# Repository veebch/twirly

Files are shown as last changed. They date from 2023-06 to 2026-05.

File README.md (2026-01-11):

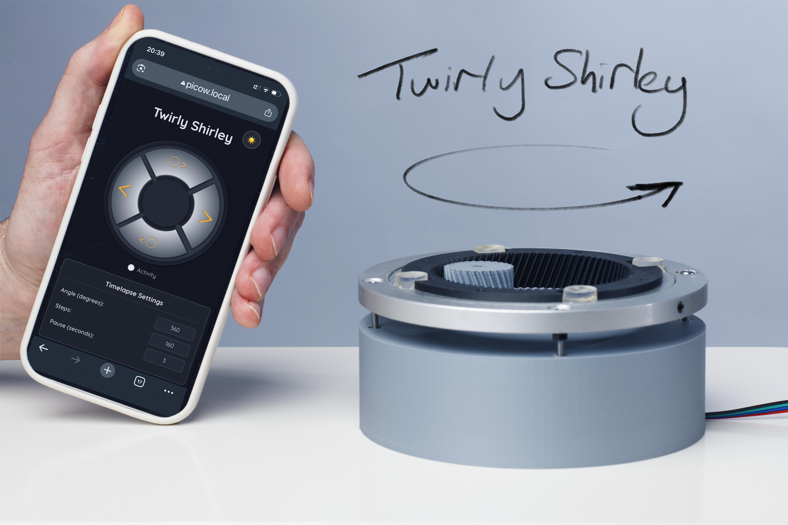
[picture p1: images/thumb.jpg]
Action Shot


 

# Twirly Shirley - WiFi Turntable

A webpage-controlled turntable system using Raspberry Pi Pico W and DRV8825 stepper motor driver. Perfect for product photography, 360° documentation, time-lapse videos and rotating things remotely.

## Demo Video

*Click [here](https://www.youtube.com/watch?v=peo0DxWtorY) to watch the full demonstration*

## Web Interface

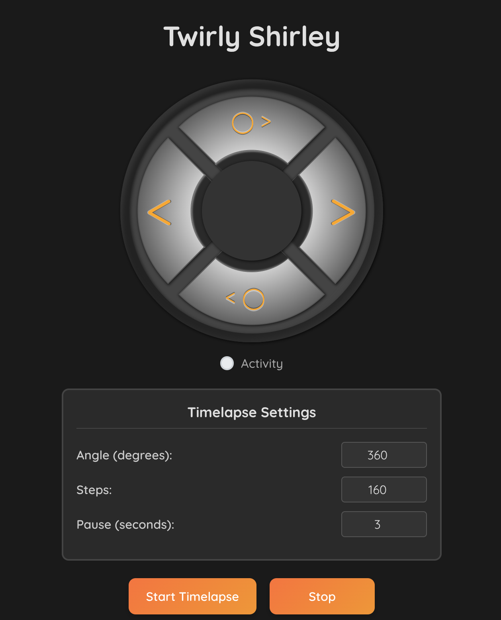
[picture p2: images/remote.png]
Remote Control Interface


The mobile-friendly web interface provides complete control over the turntable with real-time feedback and dark mode support.

## Quick Start

1. **Flash MicroPython** to your Pico W
2. **Wire the hardware** - see [WIRING.md](WIRING.md) for detailed connections
3. **Copy files** to the Pico W filesystem
4. **Power on** - Twirly will automatically start an access point for WiFi setup
5. **Connect to "pi pico" WiFi** and configure your network credentials
6. **Access** the web interface at http://picow.local 

## Key Features

- **Microstepping Control**: Smooth motion with 1-32 microstepping
- **Web Interface**: Mobile-friendly with dark mode
- **Timelapse Mode**: Automated rotation for photography
- **Network Access**: WiFi with mDNS hostname (http://picow.local) 
## Documentation

| Guide | Description |
|---|---|
| [WIRING.md](WIRING.md) | Hardware connections and setup |
| [FEATURES.md](FEATURES.md) | Complete feature list and configuration |
| [TROUBLESHOOTING.md](TROUBLESHOOTING.md) | Common issues and solutions |

## License

This project is licensed under the MIT License - see the [LICENSE](LICENSE) file for details.

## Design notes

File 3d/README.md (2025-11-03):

Action Shot

# Gears and Case

These stl files were made with [openSCAD](https://openscad.org/) and Freecad. The script that generated the stl files is also here in case you need to tweak things due to using different parts. The gears script was based on was written by @chrisspen (https://github.com/chrisspen/gears)

To regenerate the two gears, use openscad to render the gear (uncomment ringgear or wormgear) which you can then import into your CAD tool of choice (+1 for [FreeCAD](https://freecad.org)) for tweaks to the design.

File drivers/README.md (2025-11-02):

# Drivers Directory

This directory contains all the hardware driver files and technical documentation for the Twirly project.

## Core Files

- **`drv8825.py`** - Main DRV8825 stepper motor driver class
- **`drv8825_setup.py`** - Hardware initialization and configuration

## Test and Example Files

- **`drv8825_followme.py`** - Interactive control example
- **`drv8825_speeds.py`** - Speed testing utilities  
- **`drv8825_steps.py`** - Step counting examples
- **`drv8825_turns.py`** - Rotation testing
- **`test_microstepping.py`** - Microstepping validation

## Additional Hardware

- **`encoder_portable.py`** - Rotary encoder support
- **`switch.py`** - Switch/button utilities

## Documentation

- **`MICROSTEPPING_GUIDE.md`** - Technical guide to microstepping configuration

## Usage

These files are imported by the main application. The primary entry point is `drv8825_setup.py` which initializes the motor hardware.

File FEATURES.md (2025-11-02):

# Features Guide

This guide details all the features and configuration options available in the turntable controller.

## Motor Control Features

### Microstepping Control

The system supports variable microstepping resolution for smooth motion control:

| Microsteps | Resolution | Description |
|---|---|---|
| 1 (full) | 1.8°/step | Maximum torque, fastest movement |
| 2 (half) | 0.9°/step | Good balance of speed and smoothness |
| 4 (quarter) | 0.45°/step | Smoother than half-step |
| 8 (eighth) | 0.225°/step | Very smooth operation |
| 16 | 0.1125°/step | Ultra-smooth, recommended default |
| 32 | 0.05625°/step | Maximum smoothness, slower movement |

**Configuration**: Set via web interface or modify `MICROSTEPS` in `main.py`

### Speed Ramping

3-phase acceleration/deceleration system for smooth starts and stops:

1. **Acceleration Phase**: Gradually increases from start speed to target speed
2. **Constant Speed Phase**: Maintains target speed for majority of movement
3. **Deceleration Phase**: Gradually decreases to stop speed

**Benefits**:
- Prevents motor stalling on startup
- Reduces mechanical stress
- Eliminates abrupt stops
- Smoother operation for photography/videography

### Gear Ratio Compensation

Automatic adjustment for mechanical gear reduction systems:

**Default Configuration**:
- Motor gear: 20 teeth
- Turntable gear: 81 teeth  
- Gear ratio: 4.05:1

**Customization**: Modify `GEAR_RATIO` in `main.py`:
```python
GEAR_RATIO = large_gear_teeth / small_gear_teeth
```

**Effects**:
- All rotation commands automatically compensated
- Maintains accurate angular positioning
- 360° rotation produces exactly one turntable revolution

### Direction Control

- **Clockwise**: Positive rotation values
- **Counter-clockwise**: Negative rotation values
- **Automatic**: Direction determined by rotation angle

## Web Interface Features

### Responsive Design

- **Desktop Optimized**: Full-featured interface with large controls
- **Mobile Friendly**: Touch-optimized buttons and responsive layout
- **Cross-Browser**: Compatible with modern browsers

### Dark Mode

Complete theming system with automatic preference saving:

**Features**:
- Toggle between light and dark themes
- Automatic preference persistence using localStorage
- Optimized for low-light environments
- Professional appearance for studio use

**Controls**:
- Click moon/sun icon to toggle
- Preference remembered across browser sessions
- Instant theme switching without page reload

### Real-time Control

**Manual Controls**:
- Step-by-step movement (1° increments)
- Quick rotation presets (90°, 180°, 270°, 360°)
- Direction control (CW/CCW)
- Emergency stop functionality

**Live Updates**:
- Current position display
- Motor status indicators
- Network connectivity status
- Real-time feedback on all operations

### Timelapse Mode

Automated rotation system for time-lapse photography:

**Parameters**:
- **Total Rotation**: 360° (full rotation) or custom angle
- **Number of Steps**: Configurable step count for desired frame rate
- **Delay Between Steps**: Pause time for camera exposure
- **Direction**: Clockwise or counter-clockwise

**Progress Tracking**:
- Real-time step counter (Step X of Y)
- Estimated time remaining
- Visual progress indicators
- Abort capability at any time

**Use Cases**:
- Product photography turntables
- 360° object documentation
- Time-lapse videos with rotation
- Automated scanning applications

## Network Features

### WiFi Connectivity

**Primary Mode**: Connects to existing WiFi network
- Automatic connection on startup
- DHCP IP assignment
- Status LED indication

**Configuration**: Edit WiFi credentials in `main.py`:
```python
WIFI_SSID = "your_network_name"
WIFI_PASSWORD = "your_password"
```

### Access Point Fallback

**Backup Mode**: Creates standalone network when WiFi unavailable
- Network name: "Twirly"
- IP address: 192.168.4.1
- No password required
- Automatic activation on WiFi failure

### mDNS Support

**Easy Access**: Device accessible via friendly name
- URL: `http://twirly.local`
- No need to remember IP addresses
- Automatic discovery on local network
- Compatible with most modern devices

## Status Indicators

### Activity LED

Visual feedback system using onboard LED:

**Network Status**:
- **Solid ON**: Connected to WiFi
- **Slow Blink**: Access Point mode active
- **Fast Blink**: Network connection attempt

**Motor Activity**:
- **Brief Flash**: Step command executed
- **Longer Flash**: Multi-step operation
- **Duration**: Configurable via `LED_DURATION_MS`

## Configuration Options

### Motor Parameters

Located in `main.py`, easily customizable:

```python
# Microstepping configuration
MICROSTEPS = 16          # Default microstepping resolution

# Gear system
GEAR_RATIO = 81/20       # Mechanical gear reduction

# Speed settings
MAX_SPEED = 2000         # Maximum steps per second
START_SPEED = 200        # Initial ramp speed
ACCELERATION = 1000      # Steps/second² acceleration

# LED behavior  
LED_DURATION_MS = 100    # Activity flash duration
```

### Network Settings

```python
# WiFi configuration
WIFI_SSID = "your_network"
WIFI_PASSWORD = "your_password"

# Access point fallback
AP_SSID = "Twirly"
AP_PASSWORD = None       # Open network
```

### Hardware Pins

All pin assignments configurable in `drv8825_setup.py`:

```python
# Motor control pins
STEP_PIN = 2
DIR_PIN = 3  
ENABLE_PIN = 4

# Microstepping pins
M0_PIN = 6
M1_PIN = 7
M2_PIN = 8
```

## Advanced Features

### Position Tracking

- Maintains current angular position
- Accurate step counting with microstepping
- Position reset capability
- Overflow protection for continuous operation

### Error Handling

- Network timeout protection
- Motor fault detection
- Graceful degradation on errors
- Automatic recovery mechanisms

### Performance Optimization

- Efficient step timing for DRV8825 compatibility
- Minimal latency web responses
- Optimized ramp calculations
- Memory-efficient operation on microcontroller

## Extensibility

The modular design allows easy customization:

**Hardware Extensions**:
- Additional sensors (limit switches, encoders)
- Different motor drivers
- External control interfaces

**Software Modifications**:
- Custom web interface themes
- Additional movement patterns
- Integration with external systems
- Custom API endpoints

**Communication Options**:
- Serial control interface
- MQTT integration potential
- REST API expansion
- WebSocket real-time updates

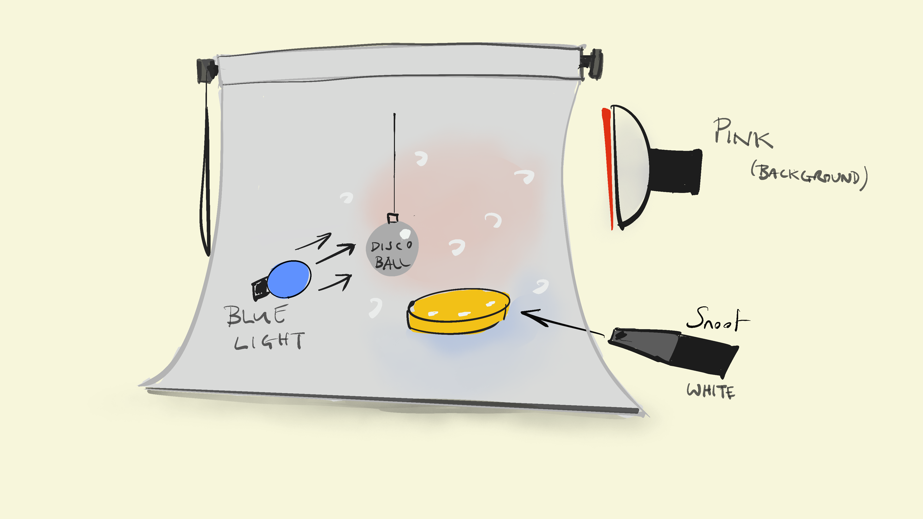
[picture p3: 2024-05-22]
images/lighting.png

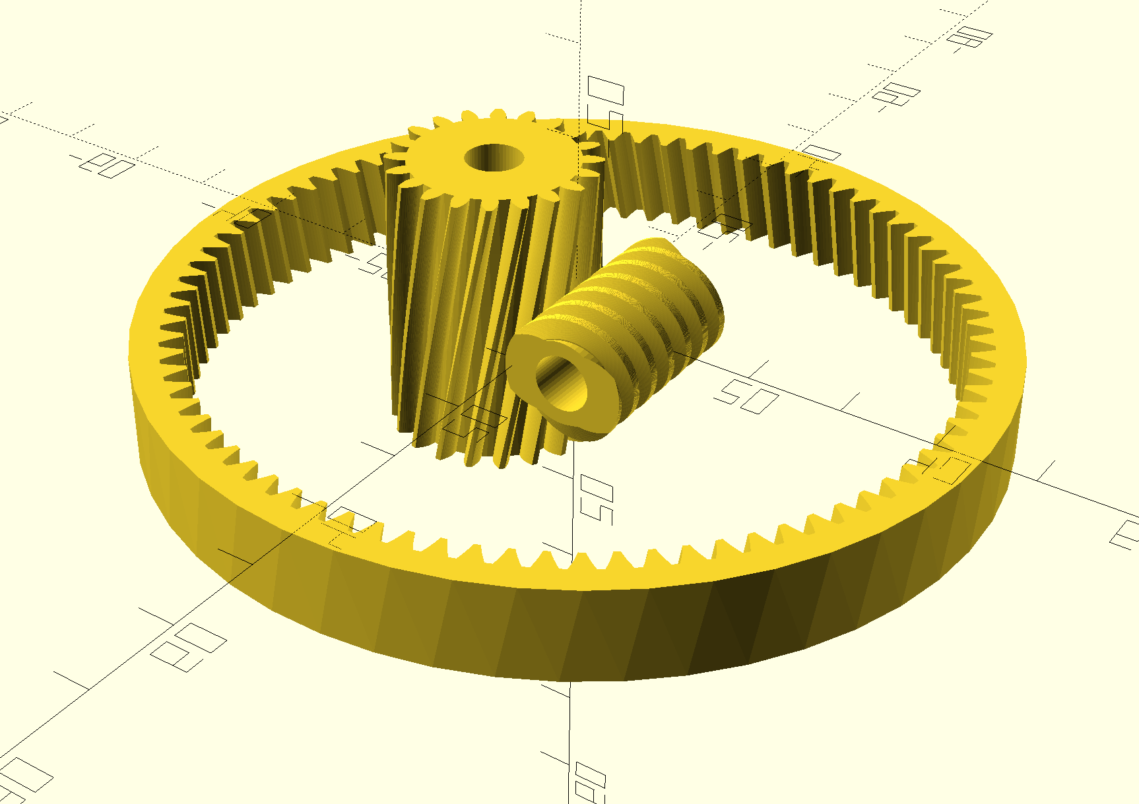
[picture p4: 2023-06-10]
images/gears.png

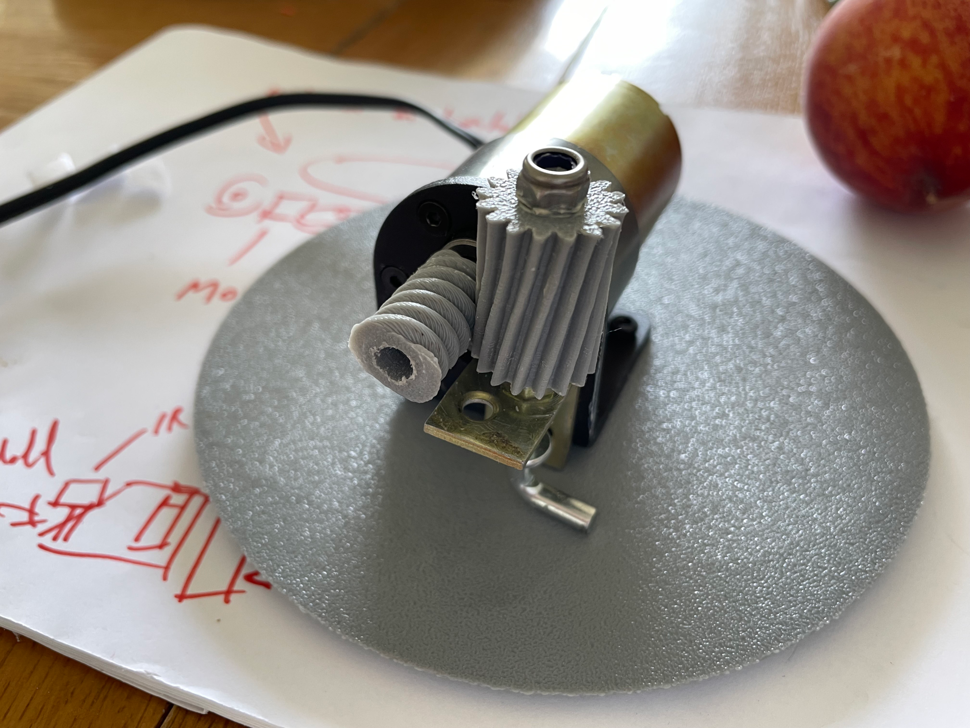
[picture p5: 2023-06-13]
images/motorworm.png

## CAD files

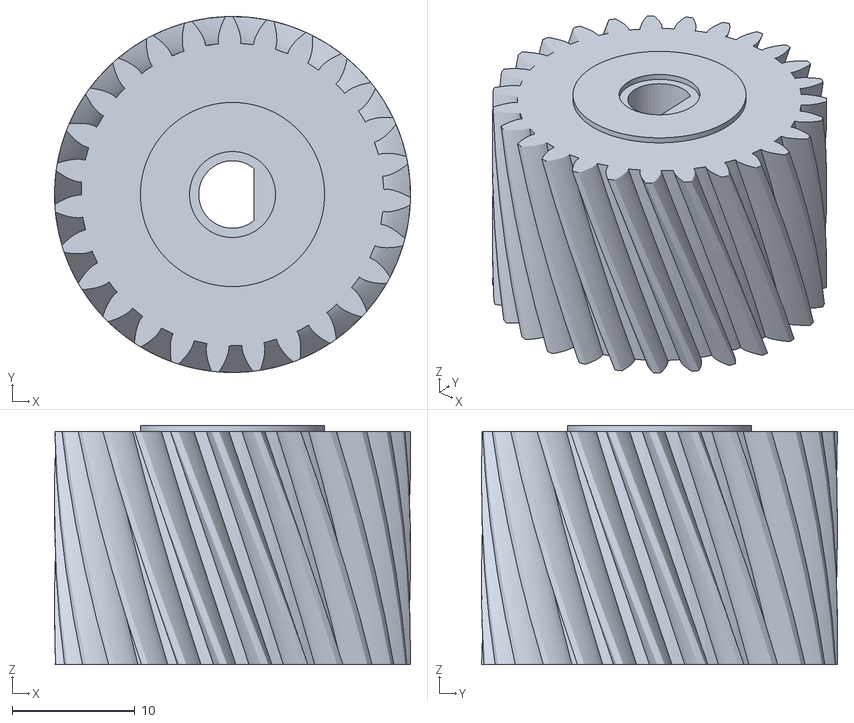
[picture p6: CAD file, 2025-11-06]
3d/gear.stl
29.0 x 29.0 x 19.5

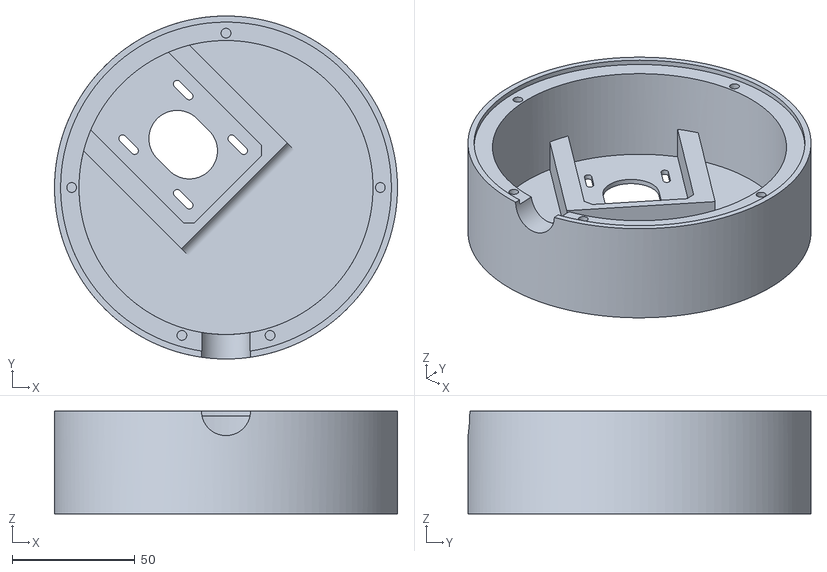
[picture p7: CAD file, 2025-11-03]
3d/twirlycase.stl
140.0 x 140.0 x 42.0

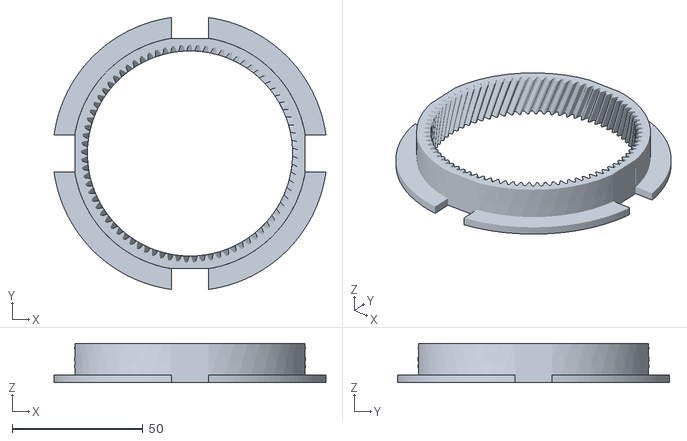
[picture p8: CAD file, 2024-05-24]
3d/ringgear.stl
104.1 x 104.1 x 15.0

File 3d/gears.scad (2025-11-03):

$fn = 50;

/* Library for Involute Gears, Screws and Racks

This library contains the following modules
- rack(modul, length, height, width, pressure_angle=20, helix_angle=0)
- mountable_rack(modul, length, height, width, pressure_angle=20, helix_angle=0, fastners, profile, head)
- herringbone_rack(modul, length, height, width, pressure_angle = 20, helix_angle=45)
- mountable_herringbone_rack(modul, length, height, width, pressure_angle=20, helix_angle=45, fastners, profile, head)
- spur_gear(modul, tooth_number, width, bore, pressure_angle=20, helix_angle=0, optimized=true)
- herringbone_gear(modul, tooth_number, width, bore, pressure_angle=20, helix_angle=0, optimized=true)
- rack_and_pinion (modul, rack_length, gear_teeth, rack_height, gear_bore, width, pressure_angle=20, helix_angle=0, together_built=true, optimized=true)
- ring_gear(modul, tooth_number, width, rim_width, pressure_angle=20, helix_angle=0)
- herringbone_ring_gear(modul, tooth_number, width, rim_width, pressure_angle=20, helix_angle=0)
- planetary_gear(modul, sun_teeth, planet_teeth, number_planets, width, rim_width, bore, pressure_angle=20, helix_angle=0, together_built=true, optimized=true)
- bevel_gear(modul, tooth_number,  partial_cone_angle, tooth_width, bore, pressure_angle=20, helix_angle=0)
- bevel_herringbone_gear(modul, tooth_number, partial_cone_angle, tooth_width, bore, pressure_angle=20, helix_angle=0)
- bevel_gear_pair(modul, gear_teeth, pinion_teeth, axis_angle=90, tooth_width, bore, pressure_angle = 20, helix_angle=0, together_built=true)
- bevel_herringbone_gear_pair(modul, gear_teeth, pinion_teeth, axis_angle=90, tooth_width, bore, pressure_angle = 20, helix_angle=0, together_built=true)
- worm(modul, thread_starts, length, bore, pressure_angle=20, lead_angle=10, together_built=true)
- worm_gear(modul, tooth_number, thread_starts, width, length, worm_bore, gear_bore, pressure_angle=20, lead_angle=0, optimized=true, together_built=true)

Examples of each module are commented out at the end of this file

Author:     Dr Jörg Janssen
Contributions By:   Keith Emery, Chris Spencer
Last Verified On:      1. June 2018
Version:    2.2
License:     Creative Commons - Attribution, Non Commercial, Share Alike

Permitted modules according to DIN 780:
0.05 0.06 0.08 0.10 0.12 0.16
0.20 0.25 0.3  0.4  0.5  0.6
0.7  0.8  0.9  1    1.25 1.5
2    2.5  3    4    5    6
8    10   12   16   20   25
32   40   50   60

*/


// General Variables
pi = 3.14159;
rad = 57.29578;
clearance = 0.05;   // clearance between teeth

/*  Converts Radians to Degrees */
function grad(pressure_angle) = pressure_angle*rad;

/*  Converts Degrees to Radians */
function radian(pressure_angle) = pressure_angle/rad;

/*  Converts 2D Polar Coordinates to Cartesian
    Format: radius, phi; phi = Angle to x-Axis on xy-Plane */
function polar_to_cartesian(polvect) = [
    polvect[0]*cos(polvect[1]),
    polvect[0]*sin(polvect[1])
];

/*  Circle Involutes-Function:
    Returns the Polar Coordinates of an Involute Circle
    r = Radius of the Base Circle
    rho = Rolling-angle in Degrees */
function ev(r,rho) = [
    r/cos(rho),
    grad(tan(rho)-radian(rho))
];

/*  Sphere-Involutes-Function
    Returns the Azimuth Angle of an Involute Sphere
    theta0 = Polar Angle of the Cone, where the Cutting Edge of the Large Sphere unrolls the Involute
    theta = Polar Angle for which the Azimuth Angle of the Involute is to be calculated */
function sphere_ev(theta0,theta) = 1/sin(theta0)*acos(cos(theta)/cos(theta0))-acos(tan(theta0)/tan(theta));

/*  Converts Spherical Coordinates to Cartesian
    Format: radius, theta, phi; theta = Angle to z-Axis, phi = Angle to x-Axis on xy-Plane */
function sphere_to_cartesian(vect) = [
    vect[0]*sin(vect[1])*cos(vect[2]),
    vect[0]*sin(vect[1])*sin(vect[2]),
    vect[0]*cos(vect[1])
];

/*  Check if a Number is even
    = 1, if so
    = 0, if the Number is not even */
function is_even(number) =
    (number == floor(number/2)*2) ? 1 : 0;

/*  greatest common Divisor
    according to Euclidean Algorithm.
    Sorting: a must be greater than b */
function ggt(a,b) =
    a%b == 0 ? b : ggt(b,a%b);

/*  Polar function with polar angle and two variables */
function spiral(a, r0, phi) =
    a*phi + r0;

/*  Copy and rotate a Body */
module copier(vect, number, distance, winkel){
    for(i = [0:number-1]){
        translate(v=vect*distance*i)
            rotate(a=i*winkel, v = [0,0,1])
                children(0);
    }
}

/*  rack
    modul = Height of the Tooth Tip above the Rolling LIne
    length = Length of the Rack
    height = Height of the Rack to the Pitch Line
    width = Width of a Tooth
    pressure_angle = Pressure Angle, Standard = 20° according to DIN 867. Should not exceed 45°.
    helix_angle = Helix Angle of the Rack Transverse Axis; 0° = Spur Teeth */
module rack(modul, length, height, width, pressure_angle = 20, helix_angle = 0) {

    // Dimension Calculations
    modul=modul*(1-clearance);
    c = modul / 6;                                              // Tip Clearance
    mx = modul/cos(helix_angle);                          // Module Shift by Helix Angle in the X-Direction
    a = 2*mx*tan(pressure_angle)+c*tan(pressure_angle);       // Flank Width
    b = pi*mx/2-2*mx*tan(pressure_angle);                      // Tip Width
    x = width*tan(helix_angle);                          // Topside Shift by Helix Angle in the X-Direction
    nz = ceil((length+abs(2*x))/(pi*mx));                       // Number of Teeth

    translate([-pi*mx*(nz-1)/2-a-b/2,-modul,0]){
        intersection(){                                         // Creates a Prism that fits into a Geometric Box
            copier([1,0,0], nz, pi*mx, 0){
                polyhedron(
                    points=[[0,-c,0], [a,2*modul,0], [a+b,2*modul,0], [2*a+b,-c,0], [pi*mx,-c,0], [pi*mx,modul-height,0], [0,modul-height,0], // Underside
                        [0+x,-c,width], [a+x,2*modul,width], [a+b+x,2*modul,width], [2*a+b+x,-c,width], [pi*mx+x,-c,width], [pi*mx+x,modul-height,width], [0+x,modul-height,width]],   // Topside
                    faces=[[6,5,4,3,2,1,0],                     // Underside
                        [1,8,7,0],
                        [9,8,1,2],
                        [10,9,2,3],
                        [11,10,3,4],
                        [12,11,4,5],
                        [13,12,5,6],
                        [7,13,6,0],
                        [7,8,9,10,11,12,13],                    // Topside
                    ]
                );
            };
            translate([abs(x),-height+modul-0.5,-0.5]){
                cube([length,height+modul+1,width+1]);          // Cuboid which includes the Volume of the Rack
            }
        };
    };
}

/* Mountable-rack; uses module "rack"
    modul = Height of the Tooth Tip above the Rolling LIne
    length = Length of the Rack
    height = Height of the Rack to the Pitch Line
    width = Width of a Tooth
    pressure_angle = Pressure Angle, Standard = 20° according to DIN 867. Should not exceed 45°.
    helix_angle = Helix Angle of the Rack Transverse Axis; 0° = Spur Teeth
    fastners = Total number of fastners.
    profile = Metric standard profile for fastners (ISO machine screws), M4 = 4, M6 = 6 etc.
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

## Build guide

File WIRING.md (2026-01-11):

# Wiring Guide

Raspberry Pi Pico GPIO Pinout

This guide provides detailed wiring instructions for connecting the Raspberry Pi Pico W to the DRV8825 stepper motor driver.

## Required Components

- Raspberry Pi Pico W
- DRV8825 Stepper Motor Driver
- NEMA stepper motor (4-wire bipolar)
- 20V PD trigger (USB-C) for motor power supply
- Step-down converter (20V to 5V) for logic power
- 100µF capacitor (for 20V supply)
- 100µF capacitor (for 5V supply)
- Breadboard or prototype board
- Jumper wires

## Assembled Components

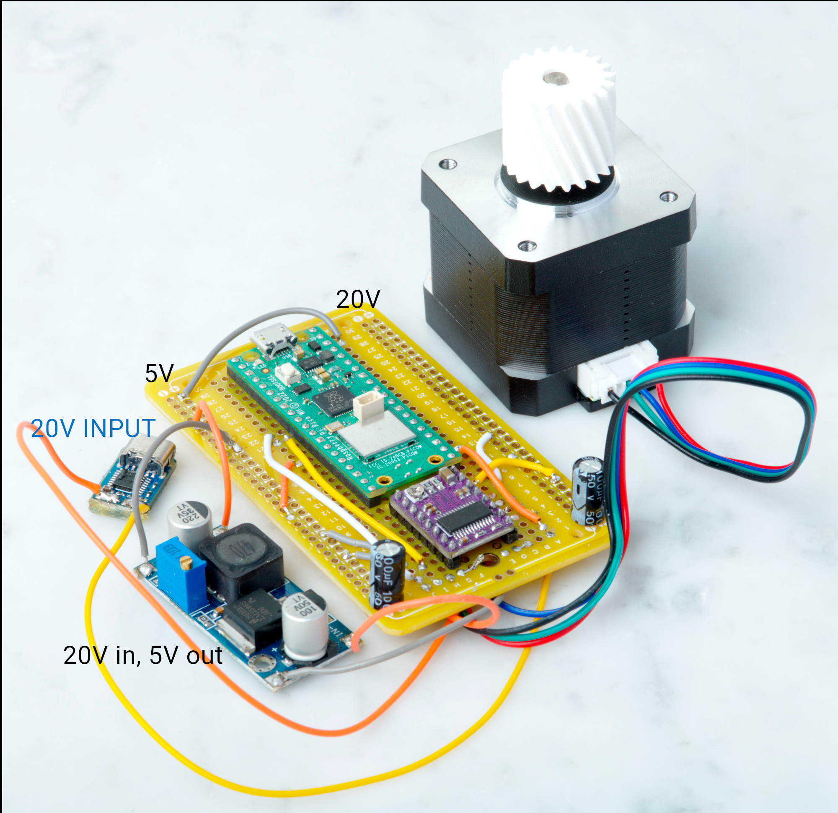
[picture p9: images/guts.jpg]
Assembled Components


*Example of the assembled system showing the Raspberry Pi Pico W, DRV8825 driver, USB-C PD trigger, and step-down converter. NB. Microstepping not connected in this image*

## Pin Connections

### Pico W to DRV8825

| Pico W Pin | DRV8825 Pin | Function |
|---|---|---|
| GP7 | STEP | Step pulse signal |
| GP6 | DIR | Direction control |
| GP8 | SLEEP | Sleep control (motor enable) |
| GP9 | RESET | Reset control |
| GP12 | M0 | Microstepping bit 0 |
| GP11 | M1 | Microstepping bit 1 |
| GP10 | M2 | Microstepping bit 2 |
| GND | GND | Common ground |

### Additional Control Pins (Optional)

| Pico W Pin | Component | Function |
|---|---|---|
| GP2 | Button/Switch | User input button |
| GP14 | End Switch 1 | Position limit switch |
| GP15 | End Switch 2 | Position limit switch |
| GP0 | Rotary Encoder A | Manual control input |
| GP1 | Rotary Encoder B | Manual control input |

### Power Supply Connections

| Connection | Description |
|---|---|
| USB-C PD Trigger 20V+ → VMOT | Motor power from PD trigger |
| USB-C PD Trigger GND → GND | Motor power ground |
| Step-down Converter 5V+ → VDD | Logic power from step-down converter |
| Step-down Converter GND → GND | Logic power ground |

**Power Supply Chain**: USB-C PD Trigger (20V) → Step-down Converter → 5V Logic Supply

### Motor Connections

Connect your 4-wire bipolar stepper motor to the DRV8825 output terminals:
- **2B, 2A**: One motor coil
- **1A, 1B**: Other motor coil

**Important**: All four motor wires must be connected for proper operation. If your motor runs, but is jerky and not in a single direction, this is likely the issue. If your motor runs, but is jerky and not in a single direction, this is likely the issue.

## Microstepping Configuration

The microstepping resolution is controlled by three pins (M0, M1, M2):

| M0 | M1 | M2 | Microsteps | Resolution |
|----|----|----|---|---|
| L  | L  | L  | 1 (full) | 1.8°/step |
| H  | L  | L  | 2 (half) | 0.9°/step |
| L  | H  | L  | 4 (quarter)| 0.45°/step |
| H  | H  | L  | 8 (eighth) | 0.225°/step |
| L  | L  | H  | 16 | 0.1125°/step |
| H  | L  | H  | 32 | 0.05625°/step |

**Note**: H = High (3.3V), L = Low (0V or floating)

## Current Limiting Setup

The DRV8825 has a built-in current limiting feature that must be properly configured:

### Step-by-Step Current Setting

1. **Calculate Target Current**: Check your motor's rated current (typically 1-2A)

2. **Measure Reference Voltage**: 
   - Connect multimeter between GND and the small potentiometer on the DRV8825
   - Measure the voltage while the driver is powered

3. **Calculate Required Voltage**:
   ```
   VREF = Current_Limit × 8 × Rsense
   ```
   For DRV8825: `VREF = Current_Limit × 8 × 0.1 = Current_Limit × 0.8`
   
   Example: For 1.5A current limit: `VREF = 1.5 × 0.8 = 1.2V`

4. **Adjust Potentiometer**: 
   - Use a small screwdriver to turn the potentiometer
   - Clockwise increases current, counter-clockwise decreases
   - Adjust until VREF matches your calculated value

### Important Safety Notes

- Set current limit BEFORE connecting the motor
- Start with a lower current and increase gradually
- Monitor motor temperature during operation
- The driver will get warm during normal operation

## Power Supply Filtering

Add capacitors near the DRV8825 to filter power supply noise:

- **100µF capacitor**: Connect across 20V PD trigger output (VMOT to GND)
- **100µF capacitor**: Connect across 5V step-down converter output (VDD to GND)

These capacitors smooth voltage fluctuations and protect against voltage spikes from the USB-C PD trigger and step-down converter.

## Wiring Checklist

Before powering on, verify:

- [ ] All pin connections are secure
- [ ] Power supply polarities are correct
- [ ] Motor wires are properly connected (all 4 wires)
- [ ] Current limit is set appropriately
- [ ] Capacitors are installed for power filtering
- [ ] No short circuits between power rails
- [ ] Common ground connections are established

## Common Wiring Issues

- **Motor not moving**: Check that all 4 motor wires are connected
- **Erratic movement**: Verify power supply filtering and current limit setting
- **Driver overheating**: Reduce current limit or improve heat dissipation
- **No response**: Check enable pin connection and power supplies

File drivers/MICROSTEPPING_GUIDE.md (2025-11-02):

# Microstepping Enhancement Guide

## Overview

This turntable project has been enhanced to use **microstepping** with **intelligent speed ramping** for smoother, more precise motor control. Microstepping divides each full step of the stepper motor into smaller increments, while speed ramping provides smooth acceleration and deceleration curves.

## Key Features

### Microstepping Benefits:
- **Smoother motion** with reduced vibration
- **Higher precision** positioning
- **Quieter operation**
- **Better low-speed performance**

### Speed Ramping Benefits:
- **Gentle acceleration/deceleration** prevents mechanical stress
- **Eliminates jerky starts/stops**
- **Reduces lost steps** at high speeds
- **Professional-quality motion** for photography/videography

## Microstepping Options

The DRV8825 driver supports the following microstepping resolutions:

| Microsteps | Resolution | Use Case | Ramping Applied |
|---|---|---|---|
| 1 | Full step | Maximum speed, basic positioning | Large moves only |
| 2 | Half step | Good balance of speed and smoothness | Large moves only |
| 4 | Quarter step | Better smoothness | Large moves only |
| 8 | 1/8 step | High precision applications | Most moves |
| 16 | 1/16 step | **Default** - Excellent smoothness | All large moves |
| 32 | 1/32 step | Maximum smoothness, slower speed | All moves |

## Speed Ramping Implementation

### When Ramping is Applied:
- **360° rotations**: Full ramping for smooth professional motion
- **Timelapse sequences**: Ramping on each movement for cinematic quality
- **Large movements**: Movements > 20 full steps equivalent
- **Small nudges**: No ramping for precise positioning
- **Tiny adjustments**: Movements < 6 full steps equivalent

### Ramping Profile:
1. **Acceleration Phase**: 15% of movement at 30-100% target speed
2. **Constant Phase**: 70% of movement at target speed
3. **Deceleration Phase**: 15% of movement at 100-30% target speed

## Web Interface Controls

### Basic Motor Controls
- **< and >**: Small nudge movements
- **◯ > and < ◯**: Full 360° rotations  
- **Title**: Timelapse sequence with ramping
- **Center button**: Emergency stop

### Microstepping Settings
- **Settings panel**: Choose from 1, 2, 4, 8, 16, or 32 microsteps
- **Status display**: Shows current microstepping configuration
- **Real-time switching**: Change settings without restarting

## API Endpoints

### Movement Controls
- `GET /cw_360` - Clockwise 360° rotation **with ramping**
- `GET /ccw_360` - Counter-clockwise 360° rotation **with ramping**
- `GET /cw_a_bit` - Small clockwise nudge **without ramping**
- `GET /ccw_a_bit` - Small counter-clockwise nudge **without ramping**
- `GET /timelapse` - Execute timelapse sequence **with ramping**
- `GET /stop` - Emergency stop

### Configuration & Testing
- `GET /microsteps?microsteps=<value>` - Set microstepping (1,2,4,8,16,32)
- `GET /microsteps` - Get current microstepping setting
- `GET /status` - Get system status including microstepping and ramping info
- `GET /test_ramping` - **NEW**: Test ramping functionality with controlled sequence

## Technical Implementation

### Speed Optimization with Ramping
The system automatically adjusts speeds and applies ramping based on microstepping resolution:

```python
# Speed scaling based on microstepping
speed = base_speed * (current_microsteps // 4)

# Intelligent ramping decision
if movement_size > microsteps * 20:
    action(steps, microsteps, speed, use_ramping=True)
else:
    action(steps, microsteps, speed, use_ramping=False)
```

### Ramping Algorithm
```python
# Three-phase movement for large motions:
# 1. Acceleration: 30% → 100% of target speed
# 2. Constant: 100% of target speed  
# 3. Deceleration: 100% → 30% of target speed
```

### Step Calculation
Physical movements are maintained by scaling step counts:

```python
# Same physical movement regardless of microstepping
steps = full_steps * current_microsteps
```

### Hardware Connections (Raspberry Pi Pico W)
- M0 pin: GPIO 12
- M1 pin: GPIO 11  
- M2 pin: GPIO 10
- STEP pin: GPIO 7
- DIR pin: GPIO 6
- SLEEP pin: GPIO 8
- RESET pin: GPIO 9

## Usage Examples

### Changing Microstepping via Web Interface
1. Open the turntable web interface
2. Use the microstepping buttons (1, 2, 4, 8, 16, 32)
3. Current setting is highlighted in orange
4. All subsequent movements use the new setting

### Changing Microstepping via API
```bash
# Set to 16 microsteps for smooth operation
curl "http://[pico-ip]/microsteps?microsteps=16"

# Set to 1 microstep for maximum speed
curl "http://[pico-ip]/microsteps?microsteps=1"

# Check current setting
curl "http://[pico-ip]/status"
```

### Testing Speed Ramping via API
```bash
# Test the ramping functionality
curl "http://[pico-ip]/test_ramping"

# Check system status (includes ramping info)
curl "http://[pico-ip]/status"
```

### Code Example with Ramping
```python
# Large movement with automatic ramping
action(steps=810 * 16, microsteps=16, speed=400, use_ramping=True)

# Small precise movement without ramping  
action(steps=6 * 8, microsteps=8, speed=200, use_ramping=False)

# Let system decide based on movement size
action(steps=100 * 16, microsteps=16, speed=300)  # Auto-ramping
```

## Recommendations

### For Different Use Cases:

**Photography/Videography**: Use 16 or 32 microsteps with ramping enabled for smooth, professional motion that eliminates camera shake

**Product Scanning**: Use 8 or 16 microsteps with ramping for good precision and smooth movement between positions

**Quick Positioning**: Use 1 or 2 microsteps - ramping automatically disabled for small moves, enabled for large moves

**Precision Work**: Use 16 or 32 microsteps with ramping for fine adjustments without vibration

### Performance Notes:
- **Ramping automatically applied** to movements > 20 full-step equivalent
- **Small nudges skip ramping** for immediate precise positioning  
- **Emergency stop works immediately** regardless of ramping state
- **Speed scaling optimized** for each microstepping level
- **Three-phase ramping** provides professional motion quality

### Motion Quality Comparison:
- **Without ramping**: Instant start/stop, possible vibration, good for tiny adjustments
- **With ramping**: Smooth acceleration/deceleration, professional quality, ideal for visible movements

## Troubleshooting

### Motor Not Moving
1. Check microstepping setting (try setting to 1 for testing)
2. Verify power supply (20V for motor, 5V for logic)
3. Check wiring connections
4. Test with lower speeds

### Jerky Movement
1. Increase microstepping (try 16 or 32)
2. Reduce speed if too high for current microstepping
3. Check for loose mechanical connections

### Web Interface Issues
1. Refresh page to reload current status
2. Check network connection to Pico W
3. Verify Pico W is running the updated firmware

## Testing

Run the test script to validate microstepping functionality:

```bash
# On the Pico W (via terminal/IDE)
python test_microstepping.py
```

This will test all microstepping configurations and validate the system is working correctly.

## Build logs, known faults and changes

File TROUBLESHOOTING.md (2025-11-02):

# Troubleshooting Guide

This guide helps diagnose and fix common issues with the turntable controller.

## Motor Issues

### Motor Not Moving

**Symptoms**: Motor doesn't rotate when commands are sent

**Causes and Solutions**:

1. **Wiring Problems** (Most Common)
   - **Check**: Verify all four motor wires are connected to DRV8825 outputs
   - **Fix**: Ensure secure connections to 2B, 2A, 1A, 1B terminals
   - **Note**: "It's always the wires" - this is the #1 cause of motor issues

2. **Power Supply Issues**
   - **Check**: Verify 20V motor supply is connected to VMOT and GND
   - **Check**: Verify 5V logic supply is connected to VDD and GND
   - **Fix**: Ensure power supplies are providing correct voltages

3. **Enable Pin Problem**
   - **Check**: ENABLE pin should be connected to GP4
   - **Check**: Motor should be enabled in software (ENABLE pin LOW)
   - **Fix**: Verify pin connection and software enable state

4. **Current Limit Too Low**
   - **Check**: Measure VREF voltage on DRV8825 potentiometer
   - **Fix**: Adjust current limit to appropriate level for your motor

### Erratic or Jerky Movement

**Symptoms**: Motor moves but skips steps, jerks, or moves inconsistently

**Causes and Solutions**:

1. **Timing Issues**
   - **Problem**: DRV8825 requires minimum 1.9μs pulse width
   - **Check**: Verify `drv8825.py` includes proper timing delays
   - **Fix**: Ensure `utime.sleep_us(2)` calls are present in step function

2. **Power Supply Noise**
   - **Problem**: Electrical noise affecting motor control
   - **Check**: Verify capacitors are installed (470µF on 20V, 100µF on 5V)
   - **Fix**: Add or replace power supply filtering capacitors

3. **Loose Connections**
   - **Check**: All wire connections for secure contact
   - **Fix**: Reseat all connections, especially power and motor wires

4. **Current Setting Issues**
   - **Problem**: Current limit too high or too low
   - **Check**: Motor temperature and movement quality
   - **Fix**: Adjust DRV8825 current limit potentiometer

### Motor Overheating

**Symptoms**: Motor or driver gets excessively hot

**Causes and Solutions**:

1. **Current Limit Too High**
   - **Check**: Measure VREF and calculate actual current limit
   - **Fix**: Reduce current limit to motor's rated current or below

2. **Continuous Operation**
   - **Problem**: Motor held in position with high current
   - **Fix**: Consider reducing hold current or using enable pin

3. **Poor Heat Dissipation**
   - **Fix**: Add heatsink to DRV8825 or improve airflow

## Network Issues

### Cannot Connect to WiFi

**Symptoms**: Device doesn't connect to your WiFi network

**Troubleshooting Steps**:

1. **Check Credentials**
   - **Verify**: WiFi name and password in `main.py` are correct
   - **Note**: WiFi names and passwords are case-sensitive

2. **Signal Strength**
   - **Check**: Device is within range of WiFi router
   - **Try**: Move closer to router during setup

3. **Network Compatibility**
   - **Check**: Router supports 2.4GHz (Pico W doesn't support 5GHz)
   - **Check**: No special characters in WiFi name or password

4. **Access Point Fallback**
   - **Solution**: Device creates "Twirly" network if WiFi fails
   - **Connect**: Join "Twirly" network and access via 192.168.4.1

### Cannot Access twirly.local

**Symptoms**: Browser can't find twirly.local address

**Troubleshooting Steps**:

1. **mDNS Support**
   - **Check**: Your device supports mDNS (most modern systems do)
   - **Alternative**: Use IP address instead (shown on device startup)

2. **Network Issues**
   - **Check**: Both device and computer are on same network
   - **Try**: Refresh/restart network connections

3. **Browser Problems**
   - **Try**: Different browser or incognito/private mode
   - **Clear**: Browser DNS cache

4. **Firewall/Security**
   - **Check**: Firewall isn't blocking mDNS traffic
   - **Try**: Temporarily disable firewall for testing

## Web Interface Issues

### Page Won't Load

**Symptoms**: Browser shows connection error or timeout

**Troubleshooting Steps**:

1. **Network Connectivity**
   - **Check**: Device and browser are on same network
   - **Try**: Ping the device IP address

2. **Device Status**
   - **Check**: Status LED shows network activity
   - **Try**: Reset device and wait for startup

3. **Browser Issues**
   - **Clear**: Browser cache and cookies
   - **Try**: Different browser or device

### Controls Don't Work

**Symptoms**: Web interface loads but buttons don't control motor

**Troubleshooting Steps**:

1. **JavaScript Issues**
   - **Check**: Browser has JavaScript enabled
   - **Check**: Browser console for error messages
   - **Try**: Hard refresh (Ctrl+F5)

2. **Network Latency**
   - **Check**: Network connection quality
   - **Try**: Wait longer for responses

3. **Device Overload**
   - **Check**: Only one user at a time
   - **Try**: Close other browser tabs/windows

## Hardware Debugging Process

When motor issues occur, follow this systematic approach:

### Step 1: Visual Inspection
- Check all wire connections
- Verify power LED indicators
- Look for loose or damaged components

### Step 2: Power Verification
- Measure 20V motor supply voltage
- Measure 5V logic supply voltage
- Check ground connections

### Step 3: Signal Testing
- Verify STEP pin pulses with oscilloscope/logic analyzer
- Check DIRECTION pin state changes
- Confirm ENABLE pin operation

### Step 4: Motor Testing
- Test motor with different current limits
- Try lower microstepping settings
- Verify motor specifications match driver capabilities

## Getting Help

If problems persist after following this guide:

1. **Check Documentation**: Review [WIRING.md](WIRING.md) and [FEATURES.md](FEATURES.md)
2. **Verify Setup**: Double-check all connections and settings
3. **Test Components**: Try with different motor or driver if available
4. **Report Issues**: Create GitHub issue with:
   - Detailed problem description
   - Hardware setup information
   - Steps already attempted
   - Any error messages or unusual behavior

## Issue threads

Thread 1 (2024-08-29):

Improvement on the documentation needed

el97, 2024-08-29:
Hi! I'm looking at your project and there is some information when it comes to the wiring that I find a little confusing. In the list of needed hardware, you haven't mentioned anything about capacitors though you are mentioning it further down. Which capacitors are you using?
It would be great if you could provide a wiring scheme since it's difficult to see how it's wired based on the picture.
Keep up the good work!

veebch, 2024-08-30:
Hey there. That's a good point. I'll make their placement more clear. The documentation was put together quickly with a 'clarify what people query' approach intended, so thankyou for the query! Greatly appreciated. I'll closed this when I've done it :)

veebch, 2024-09-05:
I've just checked and the two capactiors are connected to positive and ground for the two power supplies (20V and 5V in order to smooth the voltage a little). I'll still improve the documentation, but I thought I'd post a quick update here in case that's enough to fill in the gaps for you.

Zeltoc, 2025-03-23:
Hey Veeb, I'm wondering if you could provide a wiring scheme for this project other than that guts picture? I have everything that is required to build this for myself, but I'm a bit new to the the electronics part of this so the guts image is a bit confusing for me. Thank you!

veebch, 2025-03-26:
Hey there. The wiring schematic is a good idea and is on my to-do list (and just moved up it because of your question). In the meantime, ignore the messy photo and rely on the `main.py` code for the GPIO pin names and the written description in the `readme`. The datasheet for your motor should guide you on setting up the driver board (the wiring seems to vary depending on the exact motor you have)

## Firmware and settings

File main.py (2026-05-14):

from phew import access_point, connect_to_wifi, is_connected_to_wifi, dns, server
from phew.template import render_template
import json
import machine
import os
import utime
import _thread
import drivers.drv8825_setup as drv8825_setup
import sys
import gc  # Garbage collection for memory management

AP_NAME = "pi pico"
AP_DOMAIN = "pipico.net"
AP_TEMPLATE_PATH = "ap_templates"
APP_TEMPLATE_PATH = "app_templates"
WIFI_FILE = "wifi.json"
WIFI_MAX_ATTEMPTS = 3

# Global microstepping configuration
current_microsteps = 32  # Maximum 32x microstepping for ultra-smooth, quiet operation!

# Gear ratio configuration (motor gear teeth : turntable gear teeth)
# Motor gear: 27 teeth, Turntable gear: 81 teeth -> motor must turn 3 times per turntable rotation
GEAR_RATIO = 81 / 27  # 3.0:1 reduction - motor turns 3x to turn turntable 1x

# Global timelapse progress tracking
timelapse_running = False
timelapse_current_step = 0
timelapse_total_steps = 0

# Global command execution tracking
command_executing = False

# Try to reduce logging to save memory (if supported)
try:
    import phew.logging
    if hasattr(phew.logging, 'LOG_WARN'):
        phew.logging.LOG_LEVEL = phew.logging.LOG_WARN
    elif hasattr(phew.logging, 'WARN'):
        phew.logging.LOG_LEVEL = phew.logging.WARN
except:
    pass  # If logging config fails, continue anyway


def machine_reset():
    utime.sleep(1)
    print("Resetting...")
    machine.reset()


def setup_mode():
    print("Entering setup mode...")

    def ap_index(request):
        if request.headers.get("host").lower() != AP_DOMAIN.lower():
            return render_template(
                f"{AP_TEMPLATE_PATH}/redirect.html", domain=AP_DOMAIN.lower()
            )

        return render_template(f"{AP_TEMPLATE_PATH}/index.html")

    def ap_configure(request):
        print("Saving wifi credentials...")

        with open(WIFI_FILE, "w") as f:
            json.dump(request.form, f)
            f.close()

        # Schedule reboot to attempt connection with new credentials
        _thread.start_new_thread(machine_reset, ())
        return render_template(
            f"{AP_TEMPLATE_PATH}/configured.html", ssid=request.form["ssid"]
        )

    def ap_catch_all(request):
        if request.headers.get("host") != AP_DOMAIN:
            return render_template(
                f"{AP_TEMPLATE_PATH}/redirect.html", domain=AP_DOMAIN
            )

        return "Not found.", 404

    server.add_route("/", handler=ap_index, methods=["GET"])
    server.add_route("/configure", handler=ap_configure, methods=["POST"])
    server.set_callback(ap_catch_all)

    ap = access_point(AP_NAME)
    ip = ap.ifconfig()[0]
    dns.run_catchall(ip)


def application_mode():
    print("Entering application mode.")
    onboard_led = machine.Pin("LED", machine.Pin.OUT)
    
    # Get current IP address with retry logic for CYW43 stability
    import network
    wlan = network.WLAN(network.STA_IF)
    
    # Add retry logic for network interface issues
    ip_address = None
    for attempt in range(3):
        try:
            ip_address = wlan.ifconfig()[0]
            if ip_address and ip_address != '0.0.0.0':
                break
        except Exception as e:
            print(f"Network interface error (attempt {attempt+1}): {e}")
            if attempt < 2:
                import utime
                utime.sleep(2)  # Wait before retry
    
    if not ip_address or ip_address == '0.0.0.0':
        print("ERROR: Could not get valid IP address - network may be unstable")
        ip_address = "unknown"
    
    # Set hostname and use lwIP's built-in mDNS (if available) - but be gentle with CYW43
    hostname_set = False
    try:
        # The Pico W defaults to 'picow.local' which works well
        # No need to override - just verify it's working
        if ip_address and ip_address != "unknown":
            import lwip_mdns
            if lwip_mdns.setup_lwip_mdns('picow'):  # Use default hostname
                print("Hostname and mDNS configured (using picow.local)")
                hostname_set = True
            else:
                print("WARNING: Hostname setup had issues")
    except Exception as e:
        print(f"ERROR: Hostname/mDNS setup error: {e}")
    
    # Fallback to basic hostname setting if needed
    if not hostname_set and ip_address != "unknown":
        try:
            wlan.config(hostname='picow')  # Ensure default hostname
            print("Basic hostname confirmed as 'picow'")
            hostname_set = True
        except Exception as e2:
            print(f"ERROR: Even basic hostname failed: {e2}")
    
    # Temporarily disable custom mDNS to avoid socket conflicts with lwIP
    print("INFO: Custom mDNS announcer disabled to avoid lwIP conflicts")
    # Skip custom mDNS if network is unstable to avoid overloading CYW43
    if False:  # Temporarily disabled
        if ip_address == "unknown":
            print("WARNING: Skipping mDNS due to network instability")
        else:
            # Only use minimal mDNS announcer if network seems stable
            try:
                import mdns_announcer
                if mdns_announcer.start_mdns_announcer('twirly', ip_address, 180):  # Longer interval
                    print("mDNS announcer started (reduced frequency)")
            except Exception as e:
                print(f"INFO: mDNS announcer not started: {e}")
    
    if not hostname_set:
        print("WARNING: No hostname configured - use IP address directly")
    
    # Set up DNS catchall as backup (but only if network is stable)
    if ip_address != "unknown":
        try:
            dns.run_catchall(ip_address)
            print("DNS catchall configured")
        except Exception as e:
            print(f"WARNING: DNS catchall failed: {e}")
    
    # Print connection information
    print("\n" + "=" * 50)
    print("TWIRLY WEB INTERFACE READY")
    print("=" * 50)
    if ip_address != "unknown":
        print(f"Primary: http://picow.local")
        print(f"Backup:  http://{ip_address}")
        try:
            ssid = wlan.config('ssid')
            print(f"Network: {ssid}")
        except:
            print("Network: Connected (SSID unavailable)")
        print("\nAccess Methods:")
        print("1. http://picow.local (mDNS hostname)")
        print(f"2. http://{ip_address} (direct IP)")
        print("3. Point any domain to this IP (DNS catchall)")
    else:
        print("WARNING: Network interface unstable")
        print("Check CYW43 WiFi chip status")
        print("May need device restart")
    print("=" * 50)
    print("Web interface starting...")
    print("=" * 50 + "\n")
    
    def action(steps, microsteps=None, speed=50, use_ramping=True):
        """Execute stepper motor movement with proper microstepping"""
        global command_executing
        
        # Use global microsteps if not specified
        if microsteps is None:
            microsteps = current_microsteps
            
        print(f"DEBUG: Action - {steps} steps, {microsteps}x microsteps at {speed}Hz")
        
        # Set executing state
        command_executing = True
        
        try:
            # Use proper microstepping - this is the key fix!
            mot.steps(steps, microsteps, speed)
            
            # Wait for completion with timeout.
            # get_progress() is signed position, so compare against target steps.
            timeout_count = 0
            max_timeout = 100  # 5 seconds at 50ms intervals
            while mot.get_progress() != steps and timeout_count < max_timeout:
                utime.sleep_ms(50)
                timeout_count += 1
                
            if timeout_count >= max_timeout:
                print("DEBUG: Movement timed out, forcing completion")
                mot.disable()  # Force stop
                utime.sleep_ms(100)
                mot.enable()   # Re-enable for next movement
            else:
                print("DEBUG: Movement completed normally")
                
        except Exception as e:
            print(f"DEBUG: Exception: {e}")
        finally:
            command_executing = False
            gc.collect()

    def action_with_ramping(steps, microsteps, target_speed):
        """Execute movement with smooth acceleration and deceleration curves"""
        if steps == 0:
            return
            
        # Simplified ramping for MicroPython constraints
        total_steps = abs(steps)
        direction = 1 if steps > 0 else -1
        
        # Ramping configuration - keep it simple for real-time performance
        start_speed = max(target_speed * 0.3, 30)  # Start at 30% of target speed
        ramp_ratio = 0.15  # Use 15% of total movement for ramping
        ramp_steps = max(int(total_steps * ramp_ratio), microsteps)
        
        if total_steps < microsteps * 6:  # Too short for effective ramping
            mot.steps(steps, microsteps, target_speed)
            while mot.get_progress() > 0:
                utime.sleep_ms(20)
            return
        
        # Simple 3-phase movement: accelerate -> constant -> decelerate
        try:
            # Phase 1: Acceleration (gradual speed increase)
            accel_steps = min(ramp_steps, total_steps // 3)
            mot.steps(direction * accel_steps, microsteps, start_speed)
            while mot.get_progress() > 0:
                utime.sleep_ms(10)
            
            # Phase 2: Constant speed (main movement)
            constant_steps = total_steps - 2 * accel_steps
            if constant_steps > 0:
                mot.steps(direction * constant_steps, microsteps, target_speed)
                while mot.get_progress() > 0:
                    utime.sleep_ms(15)
            
            # Phase 3: Deceleration (gradual speed decrease)
            if accel_steps > 0:
                mot.steps(direction * accel_steps, microsteps, start_speed)
                while mot.get_progress() > 0:
                    utime.sleep_ms(10)
                    
        except Exception as e:
            print(f"Ramping error: {e}")
            # Fallback to simple movement
            remaining = total_steps - mot.get_progress() if mot.get_progress() > 0 else 0
            if remaining > 0:
                mot.steps(direction * remaining, microsteps, target_speed // 2)
                while mot.get_progress() > 0:
                    utime.sleep_ms(20)

    def app_cw_360(request):
        global command_executing, timelapse_running
        try:
            # Check if another command is already running
            if command_executing or timelapse_running:
                return "Error: Another command is already executing"
            
            # 360 degree turntable rotation accounting for gear ratio
            # Calculate steps: 200 full steps * gear ratio for actual 360° turntable rotation
            full_steps = int(200 * GEAR_RATIO)  # Account for 3.0:1 gear reduction
            # Slow full-circle speed by 5x for smoother rotation
            speed = max(50, (200 * (current_microsteps // 4)) // 5)
            action(full_steps * current_microsteps, current_microsteps, min(speed, 800), use_ramping=True)
            return f"360° CW turntable rotation completed ({current_microsteps}x microsteps, {min(speed, 800)}Hz)"
        except KeyboardInterrupt:
            print("Interrupted from Keyboard")
            return "360° CW rotation interrupted"
        except Exception as e:
            return f"360° CW rotation failed: {str(e)}"

    def app_ccw_360(request):
        global command_executing, timelapse_running
        try:
            # Check if another command is already running
            if command_executing or timelapse_running:
                return "Error: Another command is already executing"
            
            # 360 degree turntable rotation accounting for gear ratio (counter-clockwise)
            full_steps = -int(200 * GEAR_RATIO)  # Account for 3.0:1 gear reduction
            # Slow full-circle speed by 5x for smoother rotation
            speed = max(50, (200 * (current_microsteps // 4)) // 5)
            action(full_steps * current_microsteps, current_microsteps, min(speed, 800), use_ramping=True)
            return f"360° CCW turntable rotation completed ({current_microsteps}x microsteps, {min(speed, 800)}Hz)"
        except KeyboardInterrupt:
            print("Interrupted from Keyboard")
            return "360° CCW rotation interrupted"
        except Exception as e:
            return f"360° CCW rotation failed: {str(e)}"

    def app_cw_nudge(request):
        global command_executing, timelapse_running
        try:
            # Check if another command is already running
            if command_executing or timelapse_running:
                return "Error: Another command is already executing"
            
            print("CW nudge button pressed")
            # Small nudge movement with microsteps (clockwise) - no ramping for precision
            full_steps = 6
            speed = 100 * (current_microsteps // 8) if current_microsteps >= 8 else 50
            action(full_steps * current_microsteps, current_microsteps, max(speed, 50), use_ramping=False)
            return f"CW nudge completed ({current_microsteps}x microsteps)"
        except KeyboardInterrupt:
            print("Interrupted from Keyboard")
            return "CW nudge interrupted"
        except Exception as e:
            return f"CW nudge error: {e}"

    def app_ccw_nudge(request):
        global command_executing, timelapse_running
        try:
            # Check if another command is already running
            if command_executing or timelapse_running:
                return "Error: Another command is already executing"
            
            # Small nudge movement with microsteps (counter-clockwise) - no ramping for precision
            full_steps = -6
            speed = 100 * (current_microsteps // 8) if current_microsteps >= 8 else 50
            action(full_steps * current_microsteps, current_microsteps, max(speed, 50), use_ramping=False)
            return f"CCW nudge completed ({current_microsteps}x microsteps)"
        except KeyboardInterrupt:
            print("Interrupted from Keyboard")
            return "CCW nudge interrupted"
        except Exception as e:
            return f"CCW nudge failed: {str(e)}"

    def timelapse_worker(angle, steps, pause):
        """Worker function that runs timelapse in background thread"""
        global timelapse_running, timelapse_current_step, timelapse_total_steps, command_executing
        
        current_step = 0
        
        try:
            print(f"Starting timelapse: {angle}° in {steps} steps, {pause}s pause")
            
            # Calculate steps per movement accounting for gear ratio
            steps_per_rotation = int(200 * current_microsteps * GEAR_RATIO)
            steps_per_movement = int((angle / 360.0) * steps_per_rotation / steps)
            
            # Ensure minimum movement for very small angles
            if steps_per_movement == 0:
                steps_per_movement = 1
                print("Warning: Using minimum 1 microstep per movement")
            
            # Handle negative angles for direction
            if angle < 0:
                steps_per_movement = -abs(steps_per_movement)
            else:
                steps_per_movement = abs(steps_per_movement)
            
            # Speed calculation
            base_speed = 400 if current_microsteps >= 32 else 200
            
            print(f"Movement: {steps_per_movement} microsteps at {base_speed}Hz per step")
            
            # Execute timelapse sequence
            for step in range(steps):
                if not timelapse_running:
                    break
                    
                current_step = step + 1
                timelapse_current_step = current_step
                print(f"Step {current_step} of {steps}")
                
                # Start timing for total step duration (movement + pause)
                import time
                step_start = time.ticks_ms()
                
                # Direct motor control to avoid command_executing flag conflicts
                try:
                    print(f"DEBUG: Timelapse step {current_step} - {steps_per_movement} microsteps at {base_speed}Hz")
                    mot.steps(steps_per_movement, current_microsteps, base_speed)
                    
                    # Wait for completion; progress is signed, so wait for target.
                    timeout_count = 0
                    max_timeout = 100
                    while mot.get_progress() != steps_per_movement and timeout_count < max_timeout:
                        # Use simple loop for timing to avoid any scoping issues
                        for i in range(5000):
                            pass
                        timeout_count += 1
                        
                    print(f"DEBUG: Step {current_step} movement completed")
                except Exception as e:
                    print(f"Movement error in step {current_step}: {e}")
                
                # Wait for total step duration (pause includes movement time)
                if current_step < steps and timelapse_running:
                    elapsed_ms = time.ticks_diff(time.ticks_ms(), step_start)
                    remaining_ms = (pause * 1000) - elapsed_ms
                    
                    if remaining_ms > 0:
                        print(f"Step took {elapsed_ms}ms, waiting {remaining_ms}ms more for {pause}s total")
                        wait_start = time.ticks_ms()
                        while time.ticks_diff(time.ticks_ms(), wait_start) < remaining_ms:
                            if not timelapse_running:
                                break
                            time.sleep_ms(100)  # Small sleep to prevent busy waiting
                    else:
                        print(f"Step took {elapsed_ms}ms (longer than {pause}s duration), continuing immediately")
                    
            print(f"Timelapse completed: {steps} steps")
            
        except Exception as e:
            print(f"Timelapse error at step {current_step}: {str(e)}")
        finally:
            # Ensure all flags are cleared with more robust cleanup
            print("Starting timelapse cleanup...")
            timelapse_running = False
            command_executing = False
            timelapse_current_step = 0
            timelapse_total_steps = 0
            print("All timelapse flags cleared")
            
            # Longer delay to ensure web interface has time to poll and see the changes
            for i in range(50000):  # Increased delay
                pass
            
            # Force garbage collection
            gc.collect()
            print("Timelapse cleanup complete")

    def app_timelapse(request):
        global timelapse_running, timelapse_current_step, timelapse_total_steps, command_executing
        try:
            # Check if a timelapse is already running
            if timelapse_running or command_executing:
                return "Error: Timelapse already running or another command executing"
                
            # Parse query parameters with defaults
            angle = float(request.query.get('angle', 360))
            steps = int(request.query.get('steps', 160))
            pause = float(request.query.get('pause', 3.0))
            
            # Set progress tracking and execution state
            timelapse_running = True
            command_executing = True
            timelapse_current_step = 0
            timelapse_total_steps = steps
            
            # Start timelapse in background thread
            _thread.start_new_thread(timelapse_worker, (angle, steps, pause))
            
            # Return immediately while timelapse runs in background
            return f"Timelapse started: {angle}° in {steps} steps, {pause}s pause"
            
        except Exception as e:
            print(f"Timelapse start error: {str(e)}")
            timelapse_running = False
            command_executing = False
            return f"Failed to start timelapse: {str(e)}"

    def app_stop(request):
        global timelapse_running, command_executing
        try:
            # Stop any running timelapse
            timelapse_running = False
            command_executing = False
            
            # Emergency stop motor
            mot.stop()
            print("Emergency stop: all operations halted")
            return "Emergency stop executed - motor disabled, timelapse stopped"
        except KeyboardInterrupt:
            print("Interrupted from Keyboard")
            return "Stop command interrupted"
        except Exception as e:
            return f"Stop command failed: {str(e)}"

    def app_set_microsteps(request):
        """Set microstepping resolution"""
        global current_microsteps
        try:
            # Get microsteps value from query parameter
            if 'microsteps' in request.query:
                new_microsteps = int(request.query['microsteps'])
                if new_microsteps in [1, 2, 4, 8, 16, 32]:
                    current_microsteps = new_microsteps
                    return f"Microstepping set to {current_microsteps}"
                else:
                    return "Invalid microstepping value. Use: 1, 2, 4, 8, 16, or 32"
            else:
                return f"Current microstepping: {current_microsteps}"
        except Exception as e:
            return f"Error setting microsteps: {e}"
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

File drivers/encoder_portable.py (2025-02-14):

# encoder_portable.py

# Encoder Support: this version should be portable between MicroPython platforms
# Thanks to Evan Widloski for the adaptation to use the machine module

# Copyright (c) 2017-2022 Peter Hinch
# Released under the MIT License (MIT) - see LICENSE file

from machine import Pin

class Encoder:
    def __init__(self, pin_x, pin_y, scale=1):
        self.scale = scale
        self.forward = True
        self.pin_x = pin_x
        self.pin_y = pin_y
        self._x = pin_x()
        self._y = pin_y()
        self._pos = 0
        try:
            self.x_interrupt = pin_x.irq(trigger=Pin.IRQ_RISING | Pin.IRQ_FALLING, handler=self.x_callback, hard=True)
            self.y_interrupt = pin_y.irq(trigger=Pin.IRQ_RISING | Pin.IRQ_FALLING, handler=self.y_callback, hard=True)
        except TypeError:
            self.x_interrupt = pin_x.irq(trigger=Pin.IRQ_RISING | Pin.IRQ_FALLING, handler=self.x_callback)
            self.y_interrupt = pin_y.irq(trigger=Pin.IRQ_RISING | Pin.IRQ_FALLING, handler=self.y_callback)

    def x_callback(self, pin_x):
        if (x := pin_x()) != self._x:  # Reject short pulses
            self._x = x
            self.forward = x ^ self.pin_y()
            self._pos += 1 if self.forward else -1

    def y_callback(self, pin_y):
        if (y := pin_y()) != self._y:
            self._y = y
            self.forward = y ^ self.pin_x() ^ 1
            self._pos += 1 if self.forward else -1

    def position(self, value=None):
        if value is not None:
            self._pos = round(value / self.scale)  # Improvement provided by @IhorNehrutsa
        return self._pos * self.scale

    def value(self, value=None):
        if value is not None:
            self._pos = value
        return self._pos

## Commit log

2023-06-08 power to ir_rx
2023-06-09 threading for control
2023-06-10 Gear components
    [ringgear.stl, worm.stl]
2023-06-10 openscad gears
    [gears.scad]
2023-06-10 worm only
    [worm.stl]
2023-06-10 gear only
    [gear.stl]
2023-06-11 Prevent jerky direction change
    [main.py]
2023-06-12 17 teeth, 5.3 bore
    [gear.stl]
2023-06-12 25mm 15 tooth 5.7mm bore
    [gear.stl]
2023-06-12 25mm 16 tooth 5.7mm bore
    [gear.stl]
2023-07-17 switch to more affordable controller
2023-07-18 Update main.py
    added PWM for ramping
2023-08-28 No need for thread on action
2024-03-29 hidden button for timelapse
2024-03-29 added button functions
2024-03-29 stop button
2024-05-24 D hole
    [gear.stl]
2025-11-01 Implement microstepping control with comprehensive improvements
    - Add configurable microstepping support (1-32 microsteps)
    - Implement 4.05:1 gear ratio compensation for accurate positioning
    - Fix DRV8825 timing requirements (1.9μs pulse width)
    - Add dark mode web interface with localStorage persistence
    - Implement timelapse mode with progress tracking
    - Add mDNS support for twirly.local access
    - Improve network connectivity with AP fallback mode
    - Add comprehensive wiring documentation and troubleshooting guide
    - Fix phew framework compatibility for modern MicroPython
    - Add activity LED with configurable duration control
    [dns.py, drv8825.py, drv8825_setup.py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]
2025-11-02 Restructure documentation and remove emojis
    - Break up lengthy README into focused guides:
    * WIRING.md - Detailed hardware connections and setup
    * FEATURES.md - Comprehensive feature documentation
    * TROUBLESHOOTING.md - Systematic problem diagnosis
    - Create concise main README focused on quick start
    - Remove all emojis from code and documentation for professional appearance
    - Improve documentation accessibility and navigation
    - Maintain all technical detail while improving user experience
    [main.py]
2025-11-02 Complete documentation restructuring and MicroPython modernization
    Major improvements:
    - Break up lengthy README into focused guides (WIRING.md, FEATURES.md, TROUBLESHOOTING.md)
    - Modernize phew framework for current MicroPython (socket compatibility)
    - Implement proper mDNS support for twirly.local access
    - Add real-time timelapse progress tracking with threading
    - Fix timestamp display (no more [00:00] on startup)
    - Remove redundant center button and 'Emergency' from stop button
    - Improve error handling and user feedback
    - Remove all emojis for professional documentation
    Documentation is now approachable for newcomers while maintaining t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
    [dns.py, main.py, ntp.py]
2025-11-02 Fix timelapse progress display and UI responsiveness
    - Improved JavaScript progress polling with timeout handling
    - Fixed timelapse button to prevent UI blocking
    - Added error recovery for progress updates
    - Implemented proper button state management
    - Added delays to prevent page load issues
    - Enhanced real-time progress tracking during timelapse execution
2025-11-02 more stable
    [twirlycase.stl]
2025-11-02 Fix README formatting and organize files into drivers directory
    - Fix video link formatting in README
    - Move all DRV8825 and hardware files to drivers/ directory
    - Update imports to reflect new file structure
    - Add drivers/README.md to document the driver files
    - Clean up root directory for better project organization
    [drv8825.py, drv8825_followme.py, drv8825_setup.py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]
2025-11-02 Update 3D printed case design
    - Updated twirlycase.stl with improved design
    [twirlycase.stl]
2025-11-03 Tweak 3D printed case design
    - Further refinements to twirlycase.stl
    [twirlycase.stl]
2025-11-03 Update gear ratio to 27:81 (motor 27, turntable 81) and slow full-circle turns 5x
    - Set GEAR_RATIO = 81/27 (3.0:1)
    - Reduce full-circle speed in app_cw_360 and app_ccw_360 by factor 5 (min 50Hz)
    - Update related comments
2025-11-03 Add updated gear STL tweak
    [gear.stl]
2025-11-03 Fix microstepping: action function now properly uses microsteps parameter
    - Changed mot.steps(steps, 1, speed) to mot.steps(steps, microsteps, speed)
    - This enables the actual 16x microstepping instead of forcing full steps
    - Should result in much smoother motor movement
    - All movement calculations were correct, just needed to pass microsteps to motor
    [main.py]
2025-11-03 Add cassette-futurism microstepping slider to web interface
    - Add 'Smoothness: Microsteps' slider at bottom of controls
    - Cassette-futurism aesthetic: monospace font, green glow, metallic styling
    - Slider range: 1x to 32x microstepping (1,2,4,8,16,32)
    - Real-time feedback and server communication via /microsteps endpoint
    - Full dark mode support with enhanced retro styling
    - Progress track shows current setting visually
2025-11-03 Redesign microstepping control to match existing UI style
    - Replace cassette-futurism styling with consistent timelapse-params design
    - Use same background, borders, fonts as existing parameter controls
    - Add proper slider labels (1x through 32x) for clear visual reference
    - Simplified clean design that integrates seamlessly with current interface
    - Updated dark mode styles to match existing patterns
    - Maintains all functionality while improving visual consistency
2025-11-03 Remove problematic mDNS implementation for better reliability
    - Eliminate complex mDNS/hostname setup that was causing compatibility issues
    - Simplify network access to use direct IP address (more reliable)
    - Clean up status endpoint to remove mDNS references
    - Update README to reflect IP-based access instead of twirly.local
    - Keep DNS catchall for domain-based access as fallback
    - Reduces code complexity and eliminates MicroPython version dependencies
    [main.py]
2025-11-03 Implement simple hostname network access
    - Add wlan.config(hostname='twirly') for reliable http://twirly.local access
    - Update console output to show both hostname and IP address options
    - Enhance status endpoint with network access methods
    - Update README with clear network access instructions
    - Simplify network discovery after WiFi setup without complex mDNS
    [gear.stl, gears.scad]
2025-11-03 Enhance README with gear regeneration instructions
    Added instructions for regenerating gears using OpenSCAD.
2025-11-03 Simplify hostname to picow.local and clean up mDNS experiments
    - Updated README.md to use picow.local as official URL
    - Updated ap_templates/configured.html with clear picow.local instructions
    - Simplified main.py to use default picow hostname instead of custom twirly.local
    - Removed complex mDNS override attempts and debugging files
    - Embraced working default MicroPython behavior for better reliability
    - Updated 3d/twirlycase.stl
    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
    [twirlycase.stl]
2025-11-03 Remove references to deleted debug modules
    - Simplified debug functions to avoid import errors
    - Removed references to deleted mDNS testing modules
    - Cleaned up CYW43 diagnostic imports
    - Simplified cleanup code on server exit
    [main.py]
2025-11-03 Add Raspberry Pi Pico GPIO pinout image to wiring guide
2025-11-03 Update wiring guide with USB-C PD trigger setup and add assembled components photo
2025-11-06 Fix nudge consistency and improve timelapse - use microsteps for both CW/CCW nudges, add direction support and minimum step validation for timelapse
    [main.py]
2025-11-06 Fix timelapse 'local variable referenced before assignment' error - initialize current_step before loop
    [main.py]
2025-11-06 Add comprehensive debugging and variable initialization to fix timelapse 'referenced before assignment' error
    [main.py]
2025-11-06 Fix utime variable scoping issue - remove redundant local imports causing 'referenced before assignment' error
    [main.py]
2025-11-06 Complete rewrite of timelapse_worker - simplified to avoid all variable scoping issues, use existing action() function
    [main.py]
2025-11-06 Fix timelapse pause timing - replace machine.ticks_ms with utime.sleep in small chunks
    [main.py]
2025-11-06 Replace pause timing with simple busy wait loop to avoid all scoping issues
    [main.py]
2025-11-06 Fix activity LED staying lit - ensure all status flags are properly cleared after timelapse completion
    [main.py]
2025-11-06 Fix activity LED and progress tracking - avoid command_executing conflicts, add progress debugging
    [main.py]
2025-11-06 Add JavaScript debugging for progress tracking and improve LED logic - show all progress updates and fix LED state
2025-11-06 Fix timelapse button text - change 'completed' to 'executing' for timelapse start confirmation
    [main.py]
2025-11-06 Add comprehensive debugging to progress polling - track both backend and frontend behavior
2025-11-06 Add debugging alerts to track startProgressPolling function execution
    [gear.stl]
2025-11-06 Add comprehensive debugging for timelapse button click issues
2025-11-06 Fix CRITICAL: Move button handlers inside DOM load event - buttons were not working
2025-11-06 Test: Simplify timelapse button to match working buttons
2025-11-06 Add enhanced debugging to track progress polling behavior
2025-11-06 DIAGNOSTIC: Add alerts to track JavaScript execution and button setup
2025-11-07 Update capacitor value for 20V supply in WIRING.md
2025-11-07 Update description of assembled system in WIRING.md
    Clarified note about microstepping connection in the example image.
2025-11-07 Clarify wiring instructions for stepper motor
    Added clarification about motor wire connections to prevent issues.
2025-11-07 Fix wiring pin assignment for motor enable
2025-11-07 Change 470µF capacitor to 100µF in WIRING.md
    Updated capacitor specifications for power supply filtering.
2026-01-10 Add sleep connection details to wiring documentation
2026-01-10 Update sleep pin label in WIRING.md
2026-01-11 Fix import paths for encoder_portable and switch modules
    - Use relative imports (.encoder_portable, .switch) instead of absolute
    - Resolves dependency errors mentioned in GitHub issue #2
    - Users no longer need to manually move files out of drivers folder
    [drv8825_setup.py]
2026-05-14 Fix CCW/CW completion wait logic
    [main.py]
